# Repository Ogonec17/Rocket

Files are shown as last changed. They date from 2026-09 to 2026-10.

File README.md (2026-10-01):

# PLBP–SG1 · Супер ГИРД

Результаты предварительного проектирования учебной ракеты. **Текущий CAD D01 · расчёты OR04 · подготовка к изготовлению R01 · 1 октября 2026.**

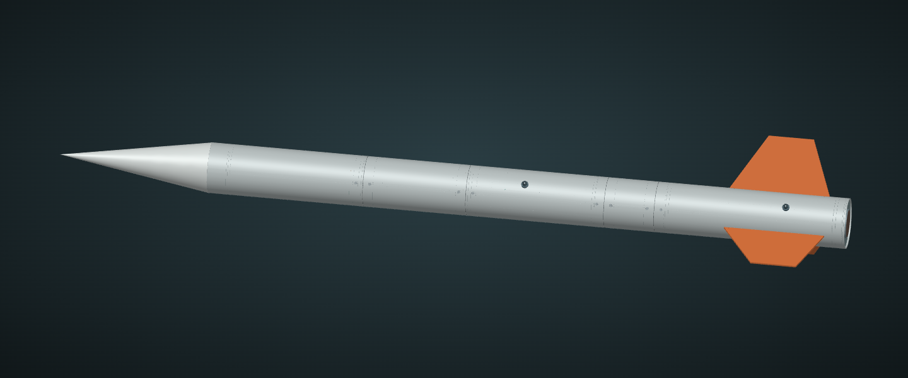
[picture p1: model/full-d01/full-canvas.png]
Модель ракеты PLBP-SG1


## Посмотреть результат

- **[Каталог чертежей DW01](drawings/index.html)** · [общий чертёж](drawings/PLBP-D01-assembly.pdf) · [все детали](drawings/PLBP-D01-parts.pdf).
- **[План сборки](assembly/assembly-plan.pdf)** · [сверка регламента](compliance/compliance-review.pdf) · [скачать комплект](drawings/PLBP-D01-team-pack.zip).

- **[Полная ракета D01: целиком, в разрезе и разнесённо](model/full-d01/viewer.html)**.
- **[Обзор готовности PDF — 6 страниц](readiness/review.pdf)** · [интерфейсы, комплектующие и испытания](readiness/README.md).
- **[Текущие расчёты OR04](simulation/or04/README.md)** — пять сценариев с массой D01.
- [Полный STEP D01](model/full-d01/PLBP-SG1-D01-FULL.step) · [что доработано](model/full-d01/README.md).

- **[Внутренний модуль E02 — предыдущая ревизия](model/internal-e02/viewer.html)** — 3D, материалы и раскрытие кассеты.
- **[Допмиссия M01](mission/m01/README.md)** — схема, алгоритм, компоненты и проверки.
- **[Расчёт OR03 для E02](simulation/or03/README.md)** — масса 5,932 кг, центровка и полёт.

- **[Презентация PDF — этап E02/M01](presentation/PLBP-SG1.pdf)** — краткая версия для команды.
- [PowerPoint](presentation/PLBP-SG1.pptx) · [автономная HTML-презентация](presentation/index.html).
- **[Архивная 3D-модель A04](model/viewer.html)** — вращение, просмотр компоновки, материалы и масса деталей.
- [Модель STEP для FreeCAD и других CAD](model/PLBP-SG1-A04.step) · [размерная схема PDF](model/layout.pdf).

- **[Внутренний модуль E01](model/internal-e01/README.md)** — 3D, размеры, материалы и детали для примерки.
- [15 дополнительных сценариев OpenRocket](simulation/or02/README.md) — влияние массы, поверхности и условий старта.

Для HTML нажмите **Download raw file**, сохраните файл и откройте его в браузере. HTML-презентация, 3D-просмотры и интерактивный отчёт автономны: дополнительные файлы и интернет для просмотра не нужны. GitHub показывает HTML как исходный текст.

## Основные параметры

| Показатель | Текущий проект |
|---|---|
| Полезная нагрузка | 1,5 кг, отдельный макет со своим спасением |
| Расчётная стартовая масса D01 | 6.136 кг, включая полезную нагрузку |
| Длина / диаметр корпуса | 1570 / 100 мм |
| Стабилизаторы | Три, вынос 110 мм |
| Задача миссии | Выведение макета на высоту не менее 1000 м, возврат и сбор данных |
| Дополнительная миссия | Независимый поиск после посадки |

Готовы цифровая компоновка, модель, ведомость масс и предварительные расчётные оценки. Массы пока не измерены. Системы спасения, реальные соединения, электроника, прочность и полёт требуют дальнейшей разработки и испытаний. Расчётный двигатель — справочный образец; конкурсный тип ещё не подтверждён.

## Конкурсная база

В [ТЗ «Супер ГИРД» XV сезона](https://lk.aesa.tech/files/15/ТЗ%20для%20СГ%202026.pdf), п. 1.1.1, масса ракеты не ограничена. При этом PDF задаёт макет **1000 г**, а [страница чемпионата](https://aesa.tech/championship) — **1500 г**. Основной проект использует 1500 г; контрольный вариант 1000 г даёт стартовую массу 5,287 кг. Масса и габарит конкурсного макета требуют подтверждения.

Опубликованное положение относится к сезону 2025–2026. Правила следующего сезона и конкурсный допуск команды ещё не подтверждены. Текущая модель — результат цифрового проектирования, не готовое к полёту изделие.

## Полёт и центровка · OR01

[Модель OpenRocket и инструкция](simulation/README.md) · [интерактивный отчёт](simulation/report.html) · [ведомость масс](simulation/mass-properties.csv).

Пять тестовых сценариев: штиль, ветер 3 и 6 м/с, направляющая 3 м вместо 4 м, контрольный шаг 0,01 с. В штиль: апогей около **1514 м**, max q **26,48 кПа**, стартовый CG **940,3 мм** от носа. Масса и CG модели OpenRocket совпали с CAD; файл повторно загружен и пересчитан.

Результаты относятся к условным входным данным и подъёму до апогея. Отделение, спасение и посадка пока не моделируются. Для открытия нужны оба файла `.ork` и `.rse`; инструкция описывает импорт двигателя. Двигатель справочный, не согласованный с организаторами.

## Уточнение OR02 / E01

[15 дополнительных расчётных случаев](simulation/or02/README.md) · [крепления внутреннего оборудования](model/internal-e01/README.md). E01: прибавка 51,9 г, условная масса ракеты 5,839 кг. Геометрия проверена; соединения, ленты и обслуживание в собранном корпусе ещё открыты. Исходная A04 и OR01 сохранены. Новые расчёты — чувствительность до апогея, не подтверждение полётом.

## Предыдущая ревизия E02 / M01 / OR03

01.10.2026: [внутренние узлы E02](model/internal-e02/README.md), [дополнительная миссия M01](mission/m01/README.md), [расчёт OR03](simulation/or03/README.md). Расчётная масса предыдущей E02 **5,932 кг** с макетом 1,5 кг. A04 и E01 сохранены как предыдущие варианты.

M01 — независимый звуковой поиск: цифровая кассета, кандидаты компонентов, цепи, программа и 17 программных проверок. Аппаратура ещё не собрана; акустический выход через закрытый корпус и зачёт миссии не подтверждены. ТЗ допускает собственный вариант допмиссии, который нужно согласовать.

Порядок следующего этапа: примерка компонентов → фиксация плат/батарей и корпусные стыки → проверка звука и давления → стенд автономности и удержания → полевые поисковые испытания. Геометрия и численный расчёт не заменяют эти проверки.

## Полная сборка D01

01.10.2026: [полная ракета](model/full-d01/viewer.html), [полный STEP](model/full-d01/PLBP-SG1-D01-FULL.step), [детализация и проверки](model/full-d01/README.md). 187 компонентов; расчётная масса 6.136 кг. Включён E02 и доработаны остальные отсеки. Старые массы/полёты E02/OR03 в других разделах относятся к предыдущему варианту.

## Обновление R01 / OR04

01.10.2026: улучшен полный 3D-просмотр D01. [Пакет готовности](readiness/README.md), [обзор PDF](readiness/review.pdf), [актуальные тестовые сценарии OR04](simulation/or04/README.md). Масса 6.136 кг; штилевой апогей 1449.1 м для гладкого контура и расчётного двигателя. Пять сохранённых и повторённых сценариев. Силовые соединения, спасение и основной борт ещё требуют завершения; изготовление и полёт не разрешены этими цифровыми проверками.

## Чертежи DW01 и план сборки AS01

[Общий чертёж — 2 листа A3](drawings/PLBP-D01-assembly.pdf) · [187 позиций, 226 листов](drawings/PLBP-D01-parts.pdf) · [каталог](drawings/index.html). [План сборки](assembly/README.md) связывает все позиции с14 операциями. [Матрица62 проверок регламента](compliance/README.md). Это проектные листы номинальной геометрии; производственные допуски и соединения ещё не выпущены. Физические испытания и допуск не подтверждены.

[Скачать единый комплект для команды](drawings/PLBP-D01-team-pack.zip): чертежи, план и сверка с рабочими локальными ссылками.

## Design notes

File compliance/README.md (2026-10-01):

# Сверка регламента · D01 / DW01 / AS01 / OR04

Проверка 01.10.2026: [официальный каталог](https://aesa.tech/documentation), [страница чемпионата](https://aesa.tech/championship). Повторно получены 9 PDF; все контрольные суммы совпали с изученной базой XV2025–2026. [Реестр источников](sources.json). [Новый XVI сезон анонсирован](https://aesa.tech/season-15-results), но технические правила следующего сезона в проверенном каталоге и поиске не найдены.

**Полное соответствие и конкурсный допуск не подтверждены.** Чертежи не закрывают физические испытания, основной борт, соединения и спасение. Школьный состав команды требует согласования для СГ. Масса макета расходится:1000 г в PDF и 1500 г на странице; проект 1500 г сохраняется до ответа.

[Матрица 62 проверок CSV](requirements.csv) · [Отчёт PDF](compliance-review.pdf) · [чертежи](../drawings/index.html) · [план сборки](../assembly/README.md).

## Как читать статусы

DOCUMENT_AVAILABLE означает наличие файла, DESIGN_ALIGNED — согласованное с пунктом проектное решение. DIGITAL_FIT_ONLY, DESIGN_ONLY, NUMERICAL_ONLY и SOFTWARE_ONLY относятся лишь к названному типу свидетельства. OPEN/EXTERNAL_OPEN/SOURCE_CONFLICT требуют действий. Ни один статус не означает лётный допуск. NOT_APPLICABLE применяется только к условным требованиям, не относящимся к нынешней одноступенчатой схеме с ПУ организаторов.

## Источники

- **REG**: [Положение_15_сезона_ВЧ_ВИШ_2026_от_04_10_2025.pdf](https://lk.aesa.tech/files/15/%D0%9F%D0%BE%D0%BB%D0%BE%D0%B6%D0%B5%D0%BD%D0%B8%D0%B5_15_%D1%81%D0%B5%D0%B7%D0%BE%D0%BD%D0%B0_%D0%92%D0%A7_%D0%92%D0%98%D0%A8_2026_%D0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).
- **APP1**: [Приложение 1 Технические_задания_2026.pdf](https://lk.aesa.tech/files/15/%D0%9F%D1%80%D0%B8%D0%BB%D0%BE%D0%B6%D0%B5%D0%BD%D0%B8%D0%B5%201%20%D0%A2%D0%B5%D1%85%D0%BD%D0%B8%D1%87%D0%B5%D1%81%D0%BA%D0%B8%D0%B5_%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).
- **APP2**: [Приложение 2 Конструкторы 2026.pdf](https://lk.aesa.tech/files/15/%D0%9F%D1%80%D0%B8%D0%BB%D0%BE%D0%B6%D0%B5%D0%BD%D0%B8%D0%B5%202%20%D0%9A%D0%BE%D0%BD%D1%81%D1%82%D1%80%D1%83%D0%BA%D1%82%D0%BE%D1%80%D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).
- **APP3**: [Приложение 3 Регламенты 2026.pdf](https://lk.aesa.tech/files/15/%D0%9F%D1%80%D0%B8%D0%BB%D0%BE%D0%B6%D0%B5%D0%BD%D0%B8%D0%B5%203%20%D0%A0%D0%B5%D0%B3%D0%BB%D0%B0%D0%BC%D0%B5%D0%BD%D1%82%D1%8B%202026.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).
- **APP4**: [Приложение 4 Перечень 2026.pdf](https://lk.aesa.tech/files/15/%D0%9F%D1%80%D0%B8%D0%BB%D0%BE%D0%B6%D0%B5%D0%BD%D0%B8%D0%B5%204%20%D0%9F%D0%B5%D1%80%D0%B5%D1%87%D0%B5%D0%BD%D1%8C%202026.pdf).
- **APP5**: [Приложение 5 Критерии 2026.pdf](https://lk.aesa.tech/files/15/%D0%9F%D1%80%D0%B8%D0%BB%D0%BE%D0%B6%D0%B5%D0%BD%D0%B8%D0%B5%205%20%D0%9A%D1%80%D0%B8%D1%82%D0%B5%D1%80%D0%B8%D0%B8%202026.pdf).
- **APP7**: [Приложение 7 Оргкомитет 2026.pdf](https://lk.aesa.tech/files/15/%D0%9F%D1%80%D0%B8%D0%BB%D0%BE%D0%B6%D0%B5%D0%BD%D0%B8%D0%B5%207%20%D0%9E%D1%80%D0%B3%D0%BA%D0%BE%D0%BC%D0%B8%D1%82%D0%B5%D1%82%202026.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).
- **APP6**: [Приложение_6_Наземные_установки_2026.pdf](https://lk.aesa.tech/files/15/%D0%9F%D1%80%D0%B8%D0%BB%D0%BE%D0%B6%D0%B5%D0%BD%D0%B8%D0%B5_6_%D0%9D%D0%B0%D0%B7%D0%B5%D0%BC%D0%BD%D1%8B%D0%B5_%D1%83%D1%81%D1%82%D0%B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).
- **SG**: [ТЗ для СГ 2026.pdf](https://lk.aesa.tech/files/15/%D0%A2%D0%97%20%D0%B4%D0%BB%D1%8F%20%D0%A1%D0%93%202026.pdf).

## Постатейная проверка

### R01 · Правила соответствующего сезона

Основание: REG, 1.11. Статус: **EXTERNAL_OPEN**.

Свидетельство: Каталог и 9 PDF повторно проверены 01.10.2026; база XV.

Закрытие: Получить ТЗ следующего сезона; XVI анонсирован, технические правила не найдены.

### R02 · Допуск состава команды в СГ

Основание: REG, 4.3.3. Статус: **EXTERNAL_OPEN**.

Свидетельство: Команда школьников; для СГ в положении перечислены другие категории.

Закрытие: Подтвердить допуск у организаторов; не заявлять регистрацию полученной.

### R03 · Капитан, руководитель, регистрация и этапы

Основание: REG, 3;5. Статус: **OPEN**.

Свидетельство: Организационная структура/заявка не предъявлены.

Закрытие: Назначить роли и пройти регистрацию по фактическому календарю.

### R04 · МГМ: масса/габарит/собственное спасение

Основание: SG, 1. Статус: **SOURCE_CONFLICT**.

Свидетельство: CAD 1500 г Ø84×220; PDF 1000 г; сайт 1500 г.

Закрытие: Согласовать массу/габарит; разработать и проверить собственное спасение макета.

### R05 · Высота ≥1000 м

Основание: SG, 1;1.1.2. Статус: **NUMERICAL_ONLY**.

Свидетельство: OR04:1449.1 м штиль со справочным мотором.

Закрытие: Пересчитать с реальным мотором, выступами и площадкой; подтвердить полётом.

### R06 · Лимит массы носителя отсутствует

Основание: SG, 1.1.1. Статус: **DESIGN_ALIGNED**.

Свидетельство: D01:6136.190 г; ограничение 1.5 кг на всю ракету снято.

Закрытие: Измерить массу; сохранять назначение 1.5 кг именно макету.

### R07 · Покупной стандартный двигатель; ΣI≤3000 Н·с

Основание: SG, 1.1.2;3.2.7. Статус: **OPEN**.

Свидетельство: Справочный K535W-REF; реальный мотор неизвестен.

Закрытие: Получить паспорт/кривую и согласовать двигатель; проверить импульс.

### R08 · Возврат:5–10 м/с последние≥10 с

Основание: SG, 1.1.3. Статус: **OPEN**.

Свидетельство: Равновесный CdA в R01; реального спасения нет.

Закрытие: Выпустить систему и протоколы раскрытия/спуска носителя и макета.

### R09 · Особое спасение: индивидуальный допуск

Основание: SG, 1.1.3 прим.. Статус: **CONDITIONAL_OPEN**.

Свидетельство: Тип системы окончательно не выбран.

Закрытие: Если система нестандартная — получить индивидуальный допуск.

### R10 · Температура

Основание: SG, 1.2.1. Статус: **OPEN**.

Свидетельство: Основной борт — концептуальная плата; схема/ПО не выпущены.

Закрытие: Выбрать датчики и алгоритм; определить диапазон/погрешность; провести стенд и запись.

### R11 · Давление

Основание: SG, 1.2.1. Статус: **OPEN**.

Свидетельство: Основной борт — концептуальная плата; схема/ПО не выпущены.

Закрытие: Выбрать датчики и алгоритм; определить диапазон/погрешность; провести стенд и запись.

### R12 · Относительная высота

Основание: SG, 1.2.1. Статус: **OPEN**.

Свидетельство: Основной борт — концептуальная плата; схема/ПО не выпущены.

Закрытие: Выбрать датчики и алгоритм; определить диапазон/погрешность; провести стенд и запись.

### R13 · Кажущаяся скорость по 3 осям

Основание: SG, 1.2.1. Статус: **OPEN**.

Свидетельство: Основной борт — концептуальная плата; схема/ПО не выпущены.

Закрытие: Выбрать датчики и алгоритм; определить диапазон/погрешность; провести стенд и запись.

### R14 · Кажущееся ускорение по 3 осям

Основание: SG, 1.2.1. Статус: **OPEN**.

Свидетельство: Основной борт — концептуальная плата; схема/ПО не выпущены.

Закрытие: Выбрать датчики и алгоритм; определить диапазон/погрешность; провести стенд и запись.

### R15 · Горизонтальное удаление

Основание: SG, 1.2.1. Статус: **OPEN**.

Свидетельство: Основной борт — концептуальная плата; схема/ПО не выпущены.

Закрытие: Выбрать датчики и алгоритм; определить диапазон/погрешность; провести стенд и запись.

### R16 · Регистрация события: Старт

Основание: SG, 1.2.2. Статус: **OPEN**.

Свидетельство: Только общая архитектура.

Закрытие: Определить критерий события, временную метку, память и телеметрию; проверить на стенде.

### R17 · Регистрация события: Апогей

Основание: SG, 1.2.2. Статус: **OPEN**.

Свидетельство: Только общая архитектура.

Закрытие: Определить критерий события, временную метку, память и телеметрию; проверить на стенде.

### R18 · Регистрация события: Команда спасения

Основание: SG, 1.2.2. Статус: **OPEN**.

Свидетельство: Только общая архитектура.

Закрытие: Определить критерий события, временную метку, память и телеметрию; проверить на стенде.

### R19 · Регистрация события: Отделение МГМ

Основание: SG, 1.2.2. Статус: **OPEN**.

Свидетельство: Только общая архитектура.

Закрытие: Определить критерий события, временную метку, память и телеметрию; проверить на стенде.

### R20 · Регистрация события: Посадка

Основание: SG, 1.2.2. Статус: **OPEN**.

Свидетельство: Только общая архитектура.

Закрытие: Определить критерий события, временную метку, память и телеметрию; проверить на стенде.

### R21 · Следующая ступень / её двигатель

Основание: SG, 1.2.2;3.2.6. Статус: **NOT_APPLICABLE**.

Свидетельство: D01 одноступенчатая.

Закрытие: При смене архитектуры повторить аудит; лимит отдельной ступени 2000 Н·с.

### R22 · Собственная приёмная станция

Основание: SG, 1.2.3. Статус: **OPEN**.

Свидетельство: Не изготовлена.

Закрытие: Реализовать радиоканал и наземную станцию; проверить данные и дальность.

### R23 · Память; инерциальная запись≥20 Гц

Основание: SG, 1.2.4;3.3.2. Статус: **OPEN**.

Свидетельство: Массовые габариты памяти и MCU в CAD.

Закрытие: Выбрать аппаратную реализацию; проверить временные метки и целостность 3 ч журнала.

### R24 · Как минимум одна дополнительная миссия

Основание: SG, 2. Статус: **SOFTWARE_ONLY**.

Свидетельство: M01: кассета, отдельное питание,17 программных проверок.

Закрытие: Закончить акустический тракт; аппаратные/поисковые испытания; согласовать зачёт.

### R25 · Повторное применение:≥2 пуска

Основание: SG, 3.1.1. Статус: **OPEN**.

Свидетельство: Цифровая сборка, прототипа нет.

Закрытие: Выпустить ресурсные проверки и процедуру осмотра после первого пуска.

### R26 · Собственный МГМ и отдельная проверка

Основание: SG, 3.1.2. Статус: **OPEN**.

Свидетельство: Носимый макет моделирован; система внутри не закончена.

Закрытие: Изготовить, испытать и отдельно предъявить комиссии.

### R27 · Питание≥3 ч

Основание: SG, 3.1.3. Статус: **OPEN**.

Свидетельство: Основной борт не выбран; для M01 есть сценарий 6 ч.

Закрытие: Испытать основной борт со всеми функциями; M01 не подменяет его энергетическую проверку.

### R28 · Смена≤5 мин либо зарядка без разбора

Основание: SG, 3.1.3. Статус: **OPEN**.

Свидетельство: Выбран путь смены; проход кассеты имеет номинальный зазор 0.2 мм.

Закрытие: Назначить допуски/жгут; выполнить смену питания в закрываемой сборке с таймером.

### R29 · Собственная ПУ: развёртывание/устойчивость

Основание: SG, 3.1.4. Статус: **NOT_APPLICABLE**.

Свидетельство: Планируется ПУ организаторов.

Закрытие: Если выбрана свояПУ: ≤1h развёртывания, устойчивость и фиксация; повторить аудит.

### R30 · Физическая блокировка исполнительных систем

Основание: SG, 3.2.1. Статус: **OPEN**.

Свидетельство: Механизм и электрическая схема не выпущены.

Закрытие: Разработать блокировки; доказать невозможность преждевременного срабатывания.

### R31 · Демонстрация безопасными LED-макетами

Основание: SG, 3.2.1 прим.2. Статус: **OPEN**.

Свидетельство: Предусмотрена в AS01 и R01, не проведена.

Закрытие: Выполнить стендовую демонстрацию по процедуре организаторов.

### R32 · Металл конструкции — только крепления

Основание: SG, 3.2.2. Статус: **DESIGN_ONLY**.

Свидетельство: Конструкционные детали GFRP/PETG; металлический крепёж; материалы условные.

Закрытие: Сверить реальный BOM и назначение металлических элементов; подтвердить материалы.

### R33 · Допустимый оборот компонентов

Основание: SG, 3.2.3. Статус: **OPEN**.

Свидетельство: Окончательной закупочной спецификации нет.

Закрытие: Проверить паспорта/происхождение выбранных компонентов в рамках допуска организаторов.

### R34 · БС 84×30×18 ±1 мм;30 г; фиксация

Основание: SG, 3.2.4. Статус: **DIGITAL_FIT_ONLY**.

Свидетельство: Кассета 87×33×21; максимальный калибр 85×31×19 помещается.

Закрытие: Примерить фактический БС; утвердить ленты/уплотнение и проверить неподвижность.

### R35 · БС вне носа; ≥5D от вершины

Основание: SG, 3.2.4. Статус: **DESIGN_ALIGNED**.

Свидетельство: БС X850; D100; требуемый отступ 500 мм.

Закрытие: Подтвердить фактическую станцию после изготовления.

### R36 · Ударная и тепловая защита БС

Основание: SG, 3.2.4. Статус: **OPEN**.

Свидетельство: Примерочная кассета; силовая и тепловая проверки отсутствуют.

Закрытие: Выпустить крепление/защиту и выполнить предусмотренные испытания.

### R37 · Вентиляция:≥8 отверстий Ø≥1.5

Основание: SG, 3.2.4. Статус: **DESIGN_ONLY**.

Свидетельство: CAD 8×Ø1.6 в X892, равномерно по окружности.

Закрытие: Проверить фактические отверстия и канал давления с закрытым корпусом и M01.

### R38 · Совместимость с ПУ

Основание: SG, 3.2.5;APP6. Статус: **OPEN**.

Свидетельство: Ползуны CAD; рельса ещё неизвестна.

Закрытие: Подтвердить профиль/длину и провести примерку; одно число 30×30 не задаёт паз.

### R39 · Выключатель борта

Основание: SG, 3.3.1. Статус: **OPEN**.

Свидетельство: Доступный внешний интерфейс не выпущен.

Закрытие: Разработать органы управления и проверить доступ в собранном корпусе.

### R40 · Параметры радио отражены в ПЗ

Основание: SG, 3.4.1–2. Статус: **OPEN**.

Свидетельство: Модуль, канал и формат ещё не выбраны.

Закрытие: Зафиксировать частоту/канал, скорость, мощность и контрольную сумму; согласовать рабочий канал.

### R41 · Передача≥5 пакетов/с

Основание: SG, 3.4.3. Статус: **OPEN**.

Свидетельство: Аппаратный канал отсутствует.

Закрытие: Проверить временные метки пакетов на 3 ч стенде и в требуемых условиях связи.

### R42 · Мощность передатчика≤1 Вт

Основание: SG, 3.4.4. Статус: **OPEN**.

Свидетельство: Передатчик не выбран.

Закрытие: Подтвердить настройку и паспорт; ограничениеТЗ не заменяет согласование частоты.

### R43 · Рекомендации: дублёр/формат/мощность

Основание: SG, 3.5. Статус: **RECOMMENDATION**.

Свидетельство: Не превращены в обязательные пороги.

Закрытие: Рассмотреть дублёр, общий формат памяти/радио и минимально достаточную мощность.

### R44 · Готовый конструктор не обязателен для СГ

Основание: APP2, конструкторы. Статус: **DESIGN_ALIGNED**.

Свидетельство: Собственная компоновка D01.

Закрытие: Показать собственные и покупные части; готовый набор не заменяет выполнениеТЗ.

### R45 · Доклад и загрузка материалов

Основание: APP3, ИКК 3;5. Статус: **OPEN**.

Свидетельство: Презентация этапа E02; актуальные чертежи/расчёты выпущены отдельно.

Закрытие: Свести презентацию в одну актуальную ревизию; проверить фактический срок загрузки и 15+15 мин регламент.

### R46 · ПЗ, свидетельства и видео

Основание: APP3, ЗОС 3–5. Статус: **OPEN**.

Свидетельство: Физических протоколов/видео нет.

Закрытие: Подготовить требуемые испытания, материалы и уведомление; общий хронометраж видео≤15 мин.

### R47 · Предстартовая проверка и итоговая защита

Основание: APP3, финал 3–5. Статус: **OPEN**.

Свидетельство: Ни изделие, ниМГМ не предъявлены.

Закрытие: Подать обновлённую ПЗ в установленный срок; предъявить изделие/МГМ/приёмник и устранить замечания.

### R48 · Двигатели организаторов

Основание: APP3, финал 5.3.6. Статус: **EXTERNAL_OPEN**.

Свидетельство: Заявлена поддержка пусков, модель не назначена.

Закрытие: Получить тип и интерфейс; два двигателя нельзя считать безусловной гарантией — число пусков может быть сокращено.

### R49 · Презентация PPTX/PDF

Основание: APP4, СГ: ИКК 1.1;ЗОС 1.2. Статус: **PARTIAL_DOCUMENT**.

Свидетельство: Есть E02/M01; D01/OR04 пока в отдельных материалах.

Закрытие: Согласовать одну актуальную версию для подачи; не маркировать старые слайды как D01.

### R50 · Архитектура, энергетика и алгоритм борта

Основание: APP4, СГ: ИКК 1.2–1.4. Статус: **PARTIAL_DOCUMENT**.

Свидетельство: Частичные материалы; основной борт не реализован.

Закрытие: Завершить схемы/алгоритм; энергобаланс в требуемом табличном и PDF форматах.

### R51 · Расчёт спасения PDF

Основание: APP4, СГ: ИКК 1.5. Статус: **PARTIAL_DOCUMENT**.

Свидетельство: R01 содержит равновесный CdA; раскрытие не рассчитано.

Закрытие: Добавить выбранные купола, нагрузки, укладку, отделение и результаты испытаний.

### R52 · Габаритный чертёж

Основание: APP4, СГ: ИКК 1.6. Статус: **DOCUMENT_AVAILABLE**.

Свидетельство: DW01: общий A3, номинальная геометрия D01.

Закрытие: Утвердить ревизию и размеры перед подачей; статус изготовления не приписывать.

### R53 · Расчёт OpenRocket

Основание: APP4, СГ: ИКК 1.7. Статус: **NUMERICAL_ONLY**.

Свидетельство: OR04:5 сценариев и 5 повторов; реальные входы открыты.

Закрытие: Пересчитать с выбранными компонентами; расширить модель на реальную миссию.

### R54 · Рекомендованы STEP и сборочный чертёж

Основание: APP4, СГ: ИКК 2.2–2.3. Статус: **DOCUMENT_AVAILABLE**.

Свидетельство: Полный STEP D01, DW01 общий вид/сечение, спецификация и AS01.

Закрытие: Выпустить окончательные соединения и допуски; AS01 пока содержит открытые точки.

### R55 · ПЗ и приложения испытаний/процедур

Основание: APP4, СГ: ЗОС 1.1;1.3. Статус: **PARTIAL_DOCUMENT**.

Свидетельство: Рабочие документы; итогового комплекта нет.

Закрытие: Собрать ПЗ в PDF, характеристики, отчёты, предстартовые/послеполётные процедуры.

### R56 · Принципиальная схема

Основание: APP4, СГ: ЗОС 1.5. Статус: **OPEN**.

Свидетельство: Есть концепция M01; основная схема не выпущена.

Закрытие: Выпустить полную принципиальную схему и жгут.

### R57 · Видео спасения, радио и отделения

Основание: APP4, СГ: ЗОС 1.6–1.8. Статус: **OPEN**.

Свидетельство: Нет.

Закрытие: Провести и записать реальные испытания трёх систем.

### R58 · Рекомендован прочностной расчёт

Основание: APP4, СГ: ЗОС 2.1. Статус: **PARTIAL_DOCUMENT**.

Свидетельство: R01: только предварительные ручные оценки.

Закрытие: Назначить нагрузки/материалы, выполнить расчёт и сопоставить с испытаниями.

### R59 · Форматы, повторная подача и сроки

Основание: APP4, общие пп.1–4. Статус: **OPEN**.

Свидетельство: Файлы доступны команде; вЛК не загружались.

Закрытие: Подать материалы заново для этапа; не менять их после закрытия без согласования.

### R60 · Оценка СГ по этапам

Основание: APP5, 6.3. Статус: **PLANNING_ONLY**.

Свидетельство: Матрица задач учитывает механику, электронику, миссии и реальные испытания.

Закрытие: Готовить свидетельства и защиту; оценки экспертов заранее не присваивать.

### R61 · Интерфейс пускового оборудования

Основание: APP6, рельса. Статус: **EXTERNAL_OPEN**.

Свидетельство: Изучено приложение; реальная рельса не получена.

Закрытие: Согласовать поперечник паза/ползунов, длину, угол и контрольную примерку.

### R62 · Контактный и экспертный состав сезона

Основание: APP7, организаторы. Статус: **REFERENCE_ONLY**.

Свидетельство: Приложение XV проверено; технических требований не добавляет.

Закрытие: Использовать актуальный канал связи; сообщения организаторам не отправлялись.

## Приоритетные несоответствия и открытые задачи

1. Согласовать сезонноеТЗ, состав команды, макет, двигатель иПУ.
2. Выпустить силовые соединения, собственное спасение макета и носителя, отделение.
3. Завершить основной борт, питание, запись, радио, наземную станцию и блокировки.
4. Подтвердить канал давления, обслуживание и M01 в закрытом корпусе.
5. Провести испытания, обновить единую презентацию/ПЗ и подать пакет своего этапа.

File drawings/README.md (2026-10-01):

# DW01 · чертежи всей ракеты и каждой позиции

[Общий чертёж — 2 листа A3](PLBP-D01-assembly.pdf) · [альбом деталей — 226 листов](PLBP-D01-parts.pdf) · [каталог](index.html) · [спецификация](catalog.csv) · [комплект ZIP](PLBP-D01-drawings.zip).

187 отдельных PDF, по одному на каждую позицию текущей модели. Повторяющиеся винты и гайки сохраняют собственные позиции; количество в каждой строке — 1. Идентификаторы P001…P187 одинаковы в чертежах, спецификации и плане сборки. Все листы имеют векторный оригинал SVG; PDF не состоит из растровых скриншотов.

## Базы и чтение

Размеры в мм, лист A3 420×297; печать 100%, без подгонки к странице. Масштаб указан у каждого вида. Это независимо подписанные ортогональные проекции X/Y, X/Z, Y/Z и вспомогательная аксонометрия, а не неявная схема расположения видов по стандарту. Пунктир — невидимые рёбра. Числа на габаритных размерных линиях — номинальный габарит в направлении соответствующей проекции; эти размеры справочные. Стрелки и рамка не означают полного соответствия ЕСКД.

Основная система: X от вершины к хвосту; Y/Z — поперечные оси CAD. Для удобства отдельные радиальные детали повернуты вокруг X; угол и последующий перенос начала указаны на листе. Таблицы цилиндрических поверхностей относятся к этой локальной системе. Они задают диаметр и прямую оси L(t)=P+t·a (P — проекция центра поверхности), но не назначают посадку, глубину глухого отверстия или резьбу. Граничный контур следует смотреть на видах и в STEP.

Проекции рассчитаны TechDraw непосредственно из BRep D01. Кривые на векторных листах аппроксимированы полилиниями с отклонением не более 0,025 мм в модельных координатах. Сечение общего чертежа получено пересечением исходной геометрии плоскостью Z=0; элементы вне плоскости не подставлены в него искусственно.

## Статус документации

Это проектные чертежи номинальной геометрии, **не утверждённые производственные чертежи**. Не назначены общие допуски, шероховатость, окончательные материалы/ламинаты, соединения и технология. Нельзя изготовлять по ним условный крепёж, платы-заглушки, складки парашюта, мотор или массовый резерв. Их листы нужны для компоновки и проверки интерфейса. [Плата Adafruit и лицензия источника](CREDITS.md) — покупная сборка с CAD изготовителя; её 58 тел не являются 58 деталями собственного производства.

Расчётная масса физических позиций 5749.163 г. Ещё 387.027 г — шесть нераспределённых бюджетов без геометрии; отдельные чертежи для них не выдуманы. Суммарная масса проекта 6136.190 г. Чертежи не изменяют CAD и массу.

[План сборки](../assembly/README.md) · [проверка требований](../compliance/README.md).

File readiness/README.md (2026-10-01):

# D01 · подготовка к изготовлению / R01

Дата: 01.10.2026. Рабочая конфигурация: полный CAD D01, полезная нагрузка 1500 г, расчётная стартовая масса 6136,190 г, CG 943,921 мм от вершины. Мотор K535W-REF — расчётный образец, не выбранный двигатель.

**Статус: компоновка проверена цифровым способом; производственный выпуск и лётный допуск не получены.** Внешних комплектующих недостаточно для закрытия проекта: необходимо завершить силовые соединения, самостоятельное спасение макета, основной борт и выводы органов управления. Ниже — задания с измеримым результатом, без вымышленных выполненных испытаний.

## Что уже определено

- Габариты 1570 × Ø100 мм; три стабилизатора с выносом 110 мм. 187 компонентов, 244 тела; номинальные пересечения отсутствуют.
- Материалы и массы сведены по деталям; плотности конструкционных материалов пока проектные. Модель изготовителя доступна для Feather RP2040; условные платы явно обозначены.
- Полезная нагрузка 1,5 кг учтена отдельно. Запас в ведомости — распределённые остатки бюджетов, а не доказанный резерв на любые новые узлы.
- Поиск M01: отдельная батарея, алгоритм и 17 программных проверок. Проверка на физической плате и слышимость через закрытый корпус остаются открытыми.
- OR04 синхронизирует массу и осевой центр масс D01 с OpenRocket. Аэродинамика использует гладкий внешний контур: выступы крепежа и направляющих не разрешены. Результаты относятся к подъёму до апогея.

## База требований

[Официальный каталог ВИШ](https://aesa.tech/documentation), [ТЗ Супер ГИРД XV сезона](https://lk.aesa.tech/files/15/ТЗ%20для%20СГ%202026.pdf), [страница чемпионата](https://aesa.tech/championship). Проверено 01.10.2026; доступная база относится к сезону 2025–2026. Требования следующего сезона и допуск школьной команды необходимо подтвердить.

В PDF макет 1000 г, Ø84×220 мм с собственной системой спасения; на странице чемпионата — 1500 г. В проекте сохраняется 1500 г, но окончательное задание и размер следует согласовать. Масса всей ракеты не ограничена. Высота ≥1000 м; суммарный импульс ≤3000 Н·с; минимум два пуска; скорость спуска 5–10 м/с в последние ≥10 с. Эти значения не являются результатами испытаний D01.

## Очерёдность завершения

| Шаг | Конкретный результат | Можно выполнить до получения мотора | Условие закрытия |
|---|---|---|---|
| R1. Требования | Утверждённые сезон, макет, двигатель, рельса и процедура блокировок | Подготовка запросов и таблицы интерфейсов | Ответ организаторов привязан к ревизии проекта |
| R2. Силовая схема | Чертежи всех соединений: хвост → кольца → корпус; стабилизаторы → моторный отсек; фалы → переборки | Выбор схемы и испытание образцов | Назначены материалы, крепления, допускаемые нагрузки и контроль; расчёт сверён с испытаниями |
| R3. Спасение | Два самостоятельных комплекта: носитель и макет; укладка, фалы, крепления, механизм разделения | Макеты отсеков и примерка выбранных куполов | Показано извлечение без зацепов, затем подтверждены раскрытие и скорость спуска |
| R4. Основной борт | Принципиальная схема, полный жгут, блокировки, ПО, наземная станция | Да | Стендовые протоколы питания, данных, записи и LED-имитации исполнительных каналов |
| R5. Обслуживание и M01 | Доступные выключатели, смена батарей, защищённый звуковой выход | Да, на отдельном макете корпуса | Смена батареи ≤5 мин; поиск в закрытом корпусе; давление у самописца не искажено новым трактом |
| R6. Производственный выпуск | Чертежи с допусками, технологией и спецификацией реальных деталей | Частично | Никаких условных габаритов в силовых и исполнительных узлах; выполнен независимый обзор |
| R7. Приёмка и сборка | Измеренные массы/CG/габариты и фактическая конфигурация ORK | После комплектования | Ведомость обновлена; интерфейсы совпадают; пройдены наземные проверки |
| R8. Допуск | Протоколы наземных испытаний и решение комиссии | Нет | Закрыты замечания, проверены реальные условия запуска |

## Конструкторские решения, которые нельзя подменять детализацией картинки

**Стыки корпуса.** В D01 стоят втулки Ø96,4/94×40 мм, условные винты M3 и круглые гайки. Требуется определить удержание гаек, доступ инструмента, фактическую длину зацепления резьбы, смятие/вырыв композита и передачу изгиба. Зазор 0,3 мм на сторону между втулкой и корпусом — номинальный, без допусков. Замена гайки на закладную должна пройти повторную проверку массы и пересечений.

**Хвост.** Посадочная труба Ø58/54,8×375 мм и габарит мотора Ø54×358 мм не задают фиксацию двигателя. Удержание и тепловая защита проектируются по инструкции конкретного покупного двигателя. Корневые части стабилизаторов входят в прорези корпуса, но соединение с трубой/кольцами и его прочность ещё не определены. Зазор 0,2 мм не является назначенным клеевым швом.

**Спасение.** Восемь складок в CAD — иллюстрация укладки. Нет выбранного купола, расчётных нагрузок раскрытия, спецификации фалов и законченного отделения. Равновесная оценка CdA из расчётного приложения помогает выбрать диапазон куполов, но не определяет усилие раскрытия. Макет должен иметь собственный комплект; размещённый внутри резерв массы не заменяет этот комплект.

**Электроника.** Основная плата и контроллер спасения пока объёмные макеты. Требуется выбрать датчики/радио/питание, выпустить схему и определить положение антенны. Предусмотреть съёмные разъёмы с фиксацией, защиту проводов от перетирания и маркировку каждого конца. Исполнительные выходы сначала проверяются на безопасных светодиодных эквивалентах.

**M01 и давление.** Отверстия внутри кассеты не выводят звук наружу. Следующее решение — отдельный акустический тракт к оболочке с защитой от попадания воды и отделением от измерительного объёма самописца. Пока его геометрия и материал мембраны не выбраны, нельзя утверждать дальность поиска. До вырезания отверстий нужен макет тракта: сравнить слышимость в закрытом корпусе и реакцию канала давления. Наружная кнопка/индикатор также требуют законченного интерфейса. Проектные цели 10 и 25 м проверяются после установки всего отсека.

## Комплект выпуска

- `interfaces.csv` — размеры, зависимость от комплектующих и документ, закрывающий каждый интерфейс.
- `procurement.csv` — позиции, которые надо выбрать/подтвердить; состояние «кандидат» не означает разрешение закупки.
- `ground-tests.csv` — методы и критерии приёмки; все физические проверки имеют статус NOT_RUN.
- `test-record.csv` — пустая форма измерений, конфигурации и заключения.
- [Расчётные таблицы](engineering.csv) и [обзор PDF](review.pdf) — предварительные расчёты по текущей массе и сценариям OR04.

Сначала закрываются R1–R6. Только после этого состояние проекта можно назвать «ждём комплектующие для испытаний». Часть работы можно вести параллельно в команде, но менять массу, крепления и отверстия без обновления CAD/ведомости/расчётов нельзя.

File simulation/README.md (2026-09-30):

# Полёт, центровка и давление · A04 / OR01

**Тестовый расчёт OpenRocket 24.12, до апогея. Полезная нагрузка 1,5 кг.** Площадка, реальная направляющая и двигатель организаторов неизвестны. Это предварительные сценарии, а не прогноз согласованного пуска.

- [Интерактивный отчёт с графиками](report.html): скачать файл и открыть в браузере; данные встроены.
- [Модель OpenRocket](PLBP-SG1-A04-OR01.ork) и обязательный [справочный двигатель](K535W-REF.rse).
- [Краткая таблица результатов](summary.csv) · [ведомость масс и центров деталей](mass-properties.csv).
- Полные временные ряды: [штиль](calm.csv), [ветер 3 м/с](wind3.csv), [ветер 6 м/с](wind6.csv), [направляющая 3 м](short_guide.csv), [шаг 0,01 с](fine_step.csv).

## Открытие и повторный расчёт

1. Установить [официальный OpenRocket 24.12](https://github.com/openrocket/openrocket/releases/tag/release-24.12). Готовый пакет содержит Java.
2. Сохранить `.ork` и `.rse`. Поместить `.rse` в папку пользовательских кривых тяги: в **Edit → Preferences → General → User-defined thrust curves** добавить папку с этим файлом. Перезапустить OpenRocket, чтобы он прочитал базу двигателей. В 24.12 кривая не встроена в `.ork`.
3. Открыть `.ork`. В конфигурации двигателя должен быть **PLBP Reference / K535W-REF**. Не подменять его одноимённым мотором из другой базы: это изменит исходные данные. Если программа сообщает об отсутствующем двигателе, сначала проверить импорт `.rse`.
4. Во вкладке **Flight simulations** сохранены пять сценариев с результатами. Выделить сценарий, выбрать **Run simulations**. Для графиков — **Plot / export**: CG location, CP location, stability margin, air pressure, Mach number и другие параметры.
5. Во вкладке **Simulation options → Simulation extensions** используется **Java class: info.openrocket.core.simulation.listeners.system.ApogeeEndListener**. Этот класс входит в официальный OpenRocket 24.12; дополнительный плагин не нужен. Он останавливает расчёт после обнаружения апогея. Удалять его имеет смысл только после разработки и добавления спасения.

Модель повторно открыта и пересчитана в новом процессе официального ядра 24.12. Предупреждение **“No recovery device defined in the simulation”** ожидаемо: объём спасения учитывается как масса, действующий парашют ещё не задан. Это предупреждение сохранено, а не скрыто.

## Что заложено в модель

| Вход | Принято для теста |
|---|---|
| Геометрия | A04: длина 1570 мм, Ø100 мм; конический нос 300 мм; 3 стабилизатора 200/90/70/110 × 3 мм |
| Стартовая масса / после выгорания | 5,787092 / 5,042092 кг, включая макет 1,5 кг |
| CG от вершины на старте / после выгорания | 940,325 / 873,735 мм |
| Материалы оболочек | Стеклопластик 1850 и полимер 1270 кг/м³ — принятые плотности, не измерения |
| Модель атмосферы | ISA, высота старта 0 м; стандартные 288,15 K и 101325 Па у уровня моря |
| Условные координаты | 45° с. ш., 0° долготы; сферическая Земля; это не предлагаемая площадка |
| Направляющая | Вертикально; 4 м эффективного направленного хода, отдельный тест 3 м |
| Ветер | Постоянный 0 / 3 / 6 м/с, направление потока 90° в соглашении OpenRocket; турбулентность 0 |
| Численный шаг | Максимальный шаг 0,02 с; контроль 0,01 с. Внутренние адаптивные шаги могут быть меньше |
| Поверхность | Normal; профиль стабилизаторов Square; реальные дефекты и выступающие крепления не определены |
| Массовая модель | Масса и CG каждой детали из CAD/ведомости; внутренние блоки заменены цилиндрическими сосредоточенными массами |
| Область расчёта | Одна жёсткая сборка до апогея; макет удерживается внутри |

Длина 4 м — условный эффективный ход. Реальная полезная длина рельса, положение направляющих элементов и их аэродинамика требуют согласования. В этой ревизии геометрия направляющих элементов не добавлена.

Внешняя аэродинамическая форма перенесена в компоненты OpenRocket. Массовые поправки отдельных деталей обеспечивают совпадение массы и продольного CG с CAD; фиксированная масса всей ракеты не задавалась. Поэтому расход двигателя сдвигает CG. Моменты инерции внутренних блоков приближённые; малое поперечное смещение CG около 0,254 мм сохранено в массовой модели, но это не доказывает полную модель динамики асимметрии.

## Двигатель — только справочный вход

Файл **K535W-REF.rse** содержит оцифрованную кривую коммерческого AeroTech K535W из [брошюры производителя](https://d3l66gvjdr7rqw.cloudfront.net/Templates/170652/myimages/dms%20brochure%202021-ldrs-39%20small_1656455641142.pdf). Это не сертифицированный файл и не выбор конкурсного двигателя. Масса загруженного двигателя 1264 г, расходуемая масса 745 г, Ø54 × 358 мм взяты как проектный справочный вариант; [карточка производителя](https://aerotech-rocketry.com/products/product_79e0eada-ff52-f94c-c6ad-1fdd480dbc43).

Интеграл оцифрованной кривой **1422,716 Н·с**, паспортный ориентир 1434 Н·с: расхождение −0,79%. Растровая оцифровка даёт пик около 712 Н вместо каталожных 655 Н; следовательно, расчёт ускорений и схода особенно чувствителен к замене исходной кривой. Таблица заканчивается на 2,765625 с. Расход массы считается пропорциональным накопленному импульсу, CG двигателя принят посередине корпуса и не перемещается внутри него. Событие вышибного заряда не моделируется. Геометрия двигателя внутри и его изготовление не входят в проект этой интеграции.

## Результаты

| Тест | Апогей, м | max q, кПа | Скорость схода, м/с | Смещение у апогея, м |
|---|---:|---:|---:|---:|
| Штиль · 4 м | 1514 | 26,48 | 29,3 | 1,5 |
| Ветер 3 м/с · 4 м | 1508 | 26,50 | 29,3 | 125,2 |
| Ветер 6 м/с · 4 м | 1489 | 26,55 | 29,3 | 241,9 |
| Ветер 3 м/с · 3 м | 1507 | 26,50 | 25,6 | 133,5 |
| Штиль · шаг 0,01 с | 1514 | 26,48 | 29,3 | 1,5 |

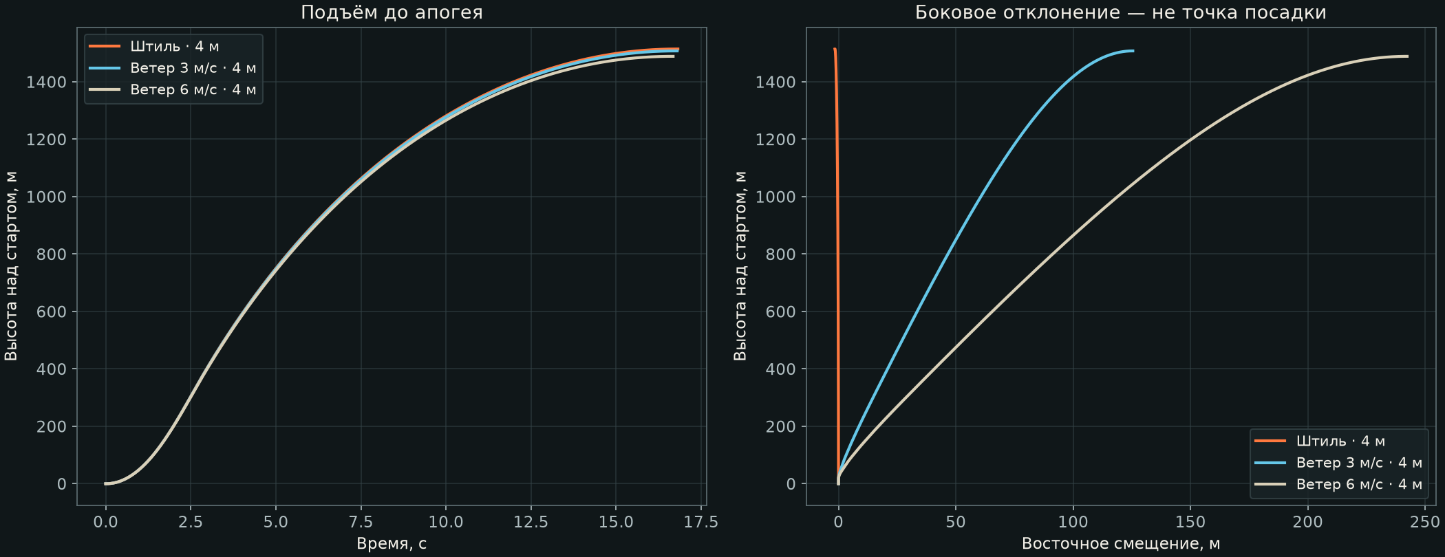
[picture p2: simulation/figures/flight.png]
Траектории тестовых сценариев


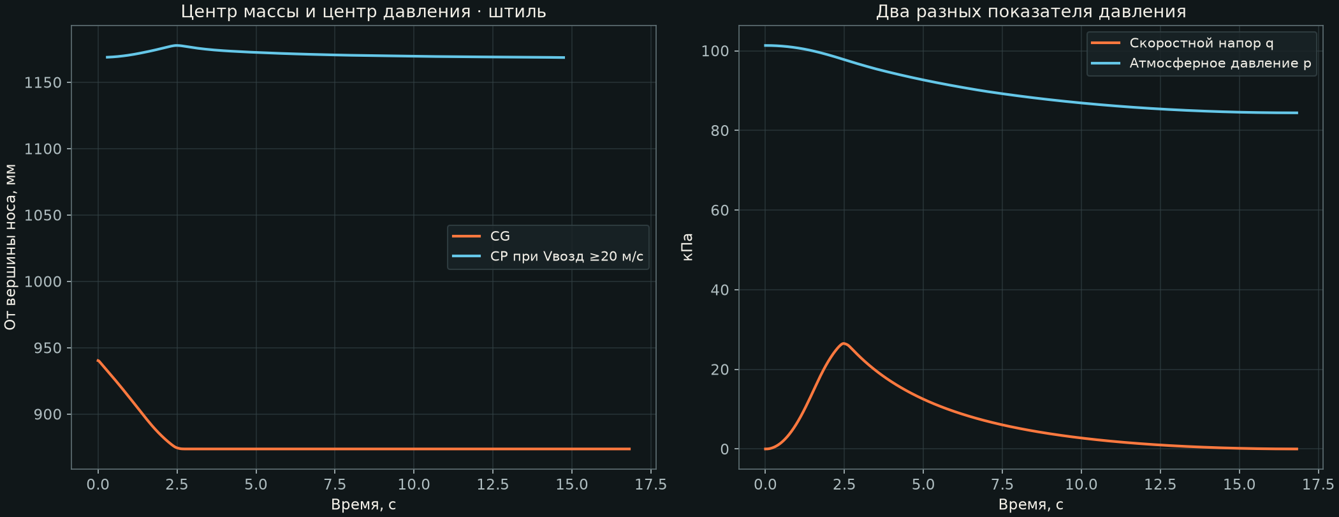
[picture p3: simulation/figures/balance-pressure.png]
Центровка, атмосферное давление и скоростной напор


Высоты даны над стартом. **Смещение у апогея не является местом посадки.** Для 6 м/с минимум расчётного запаса после схода при Vвозд ≥20 м/с составляет 1,515 диаметра, максимальный угол атаки в этом интервале — 11,5°. Это требует проверки динамики и применимости аэродинамической модели; отсутствие предупреждения симулятора не означает допуск. Неизвестная турбулентность и порывы в этих пяти сценариях отсутствуют.

В штиль max q = **26,48 кПа** при t ≈ 2,47 с, h ≈ 298 м. Максимальное число Маха 0,622. Атмосферное давление у апогея около 84,41 кПа.

## Центр масс, центр давления и запас

CG = Σ(mᵢxᵢ)/Σmᵢ. Координата x отсчитывается от вершины носа к хвосту. На старте CG = 940,325 мм; после выгорания 873,735 мм: расход массы сзади смещает центр вперёд. В [ведомости](mass-properties.csv) каждая деталь и двигатель учтены один раз; суммарно 5,787092 кг. Макет 1,5 кг — часть этой массы.

CP — точка результирующей нормальной аэродинамической силы в принятой модели. **CP не постоянен.** В статической оценке OpenRocket при M=0,05, α=0°, азимуте потока 0°: CP = **1168,8 мм**, запас (CP−CG)/D = **2,285 D**, где D=100 мм. Предыдущая ручная низкоскоростная оценка давала 1168,8 мм и 2,285 D; это другой уровень приближения, её не подгоняли к OpenRocket.

| Число Маха | Угол атаки, ° | CP от носа, мм | Запас при стартовом CG, D |
|---|---:|---:|---:|
| 0,05 | 0 | 1168,8 | 2,285 |
| 0,05 | 5 | 1124,7 | 1,844 |
| 0,05 | 10 | 1092,3 | 1,520 |
| 0,30 | 0 | 1170,5 | 2,302 |
| 0,30 | 5 | 1126,4 | 1,861 |
| 0,30 | 10 | 1094,0 | 1,537 |
| 0,60 | 0 | 1176,8 | 2,365 |
| 0,60 | 5 | 1132,8 | 1,924 |
| 0,60 | 10 | 1100,2 | 1,599 |

Положительный статический запас сам по себе не подтверждает устойчивость на направляющей, при порывах, больших углах атаки, отделении или флаттере. В графиках CP скрыт при Vвозд <20 м/с, чтобы низкоскоростную область возле апогея не принимать за надёжный показатель; исходный CSV сохранён полностью.

## Давление: три разных величины

- **Атмосферное p**, Па: давление окружающего воздуха. Меняется с высотой; для нагрузки на замкнутую оболочку нужна разность наружного и внутреннего давления. Внутреннее давление, продувка вентиляционных отверстий и переходные процессы не рассчитаны.
- **Скоростной напор q = ½ρVвозд²**, Па: масштаб аэродинамических нагрузок. Использована скорость относительно воздуха `Mach × speed_of_sound`, а не скорость относительно земли. График q не показывает локальную нагрузку каждой точки корпуса.
- **Местное давление на поверхности** требует распределения коэффициента давления, CFD или испытаний. Его здесь нет. Центр давления CP — координата, а не величина давления. Давление в двигателе не является входом этого расчёта: двигатель задан готовой кривой тяги.

## Проверки и пределы точности

Повторная загрузка `.ork` + `.rse`: без предупреждений загрузчика; пять сценариев пересчитаны; массы и продольный CG совпали с CAD до 10⁻⁸ кг/м. Это проверка переноса данных, а не точность реального изделия. Полные CSV проверены на конечность основных величин, физические знаки и массу после выгорания. Остановка после апогея сохранена в файле и повторно проверена.

При изменении шага 0,02 → 0,01 с изменение апогея составляет **0,0161 м** (0,00107%), max q — **0,402 Па**. Сравнение двух шагов даёт оценку чувствительности; оно не устанавливает порядок сходимости и не подтверждает реальный полёт.

Автоматический контроль использует seed **20260930**. В 24.12 seed не сохраняется в формате `.ork` 1.10, а ядро добавляет малые случайные моменты даже при нулевой турбулентности; повтор в GUI может немного отличаться. Сохранённые данные в `.ork` соответствуют приложенным CSV. Пакет не зависит от внешнего кода для остановки на апогее: использован штатный класс симулятора.

Это шестистепенная модель жёсткого тела с инженерной аэродинамической моделью OpenRocket, а не CFD, прочностной анализ или модель гибкой конструкции. Старый вертикальный расчёт при заданных Cd остаётся отдельной оценкой чувствительности и не смешан с новой таблицей. Отделение 1,5 кг и два парашюта нужно разработать до расчёта спуска и зоны посадки.

Для повышения достоверности нужны: согласованный двигатель с проверенной кривой тяги/массы; измеренные масса, CG и инерция сборки; реальная направляющая; метеопрофиль; геометрия креплений; стендовые проверки отделения и раскрытия; сопоставление расчёта с телеметрией испытаний.

Источники методов: [документация OpenRocket](https://openrocket.readthedocs.io/en/latest/user_guide/advanced_flight_simulation.html), [техническое описание](https://openrocket.sourceforge.net/techdoc.pdf), [штатная остановка на апогее в 24.12](https://github.com/openrocket/openrocket/blob/release-24.12/core/src/main/java/info/openrocket/core/simulation/listeners/system/ApogeeEndListener.java). Документация latest может описывать функции новее 24.12; данный файл проверен именно в 24.12.

CSV: все заголовки содержат SI-единицы; `aoa_rad` и угловые скорости — радианы, `stability_cal` — диаметры корпуса, `cg_m`/`cp_m` — от носа, `east_m`/`north_m` — локальное смещение, `ground_speed_m_s` — полная скорость относительно земли, `air_speed_m_s` — относительно воздуха. `q_Pa` вычислен из выходов атмосферы и числа Маха OpenRocket; остальные столбцы — выходы симулятора. Больше знаков в CSV нужно для воспроизводимости, а не для обещания такой точности.

## Расширение OR02

[Новая серия из 15 расчётных случаев](or02/README.md): поверхность, температура, высота площадки, запас массы, профили ветра и примерочный E01.

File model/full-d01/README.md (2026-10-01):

# D01 · полная детализированная ракета

**Полная сборка в миллиметрах, масштаб 1:1.** Это следующая цифровая ревизия после отдельного модуля E02. Внешние основные размеры: длина 1570 мм, корпус Ø100 мм, три стабилизатора с выносом 110 мм.

[Открыть полную 3D-модель](viewer.html) · [полный STEP](PLBP-SG1-D01-FULL.step) · [размерная схема PDF](layout.pdf) · [все детали и остатки бюджетов](parts.csv) · [масса по подсистемам](mass-totals.csv).

Просмотр работает без сети и внешних библиотек. WebGL со сглаживанием и разрешением экрана; при недоступности графического контекста включается резервный CPU-рендер. Режимы: целая ракета, продольный разрез, разнесение подсистем. Подсистемы можно скрывать; выбор отдельной детали приближает её. Shift + мышь перемещает камеру; доступны виды сбоку/объёмный, вписывание, полный экран и три уровня качества. Стрелки и +/− работают при фокусе на модели. Перерисовка происходит по действию пользователя, без постоянного цикла в фоне. Разрешение ограничено 1 / 3,2 / 6 млн пикселей для экономного / автоматического / высокого качества; высокое даёт дополнительное сглаживание на обычном экране. Большая детализация может требовать нескольких секунд при первом открытии на слабом ПК. На GitHub сначала скачать HTML через Download raw file. В исходном проекте дополнительно выпущены нативные FreeCAD для полной сборки и разреза, с сохранённой историей построения.

Полная ракета

## Реальная детализация этой ревизии

- **Корпус:** пять отдельных секций, четыре соединительные втулки, швы с прокладками, отверстия, винты с углублениями под ключ и ответные гайки. Их номинальная посадка проверена; резьба не моделируется, способ удержания гаек и рабочие нагрузки ещё не назначены.
- **Обтекатель:** полая оболочка, посадочная юбка, переборка, шайба и габарит рымового интерфейса. Соединение и система возврата требуют силовой проверки.
- **Полезная нагрузка:** оболочка Ø84×220, две съёмные крышки, четыре стойки и винты, опора и направляющие. Внутри явно сохранён резерв объёма/массы под собственную систему и балансировку. Это проект собственного макета, не утверждённая конструкция организаторов.
- **Спасение:** мешок, торцевые элементы, восемь условных складок купола и две ленты. Модель показывает расположение, но не предсказывает деформации ткани и раскрытие. Фалы, точки удержания и исполнительный механизм ещё не выпущены.
- **Электроника:** весь E02 включён в ракету. Основной борт и отдельный блок спасения получили корпуса, крышки и концептуальные платы размещения. Трасса основного питания показана двумя отдельными проводами с выходами через соединители. Основная схема и полный жгут остаются открытыми.
- **M01:** вместо простого габарита Feather использован [STEP Adafruit](CREDITS.md), включая USB-разъём, отверстия и электронные компоненты. Геометрия изготовителя не масштабировалась; её посадка в кассете проверена. Батарея, плата ключа и излучатель остаются в собственной кассете. Слышимость через корпус по-прежнему требует стенда.
- **Хвост:** моторная труба, кольца с технологическими отверстиями, ответная хвостовая плита и сквозные корневые части трёх стабилизаторов. Двигатель остаётся закрытым паспортным габаритом покупного изделия. Реальный удерживающий узел зависит от двигателя организаторов.
- **ПУ:** две площадки по кривизне корпуса, ползуны и крепёж. Размеры ползунов проектные; совместимость с реальной направляющей не объявлена.

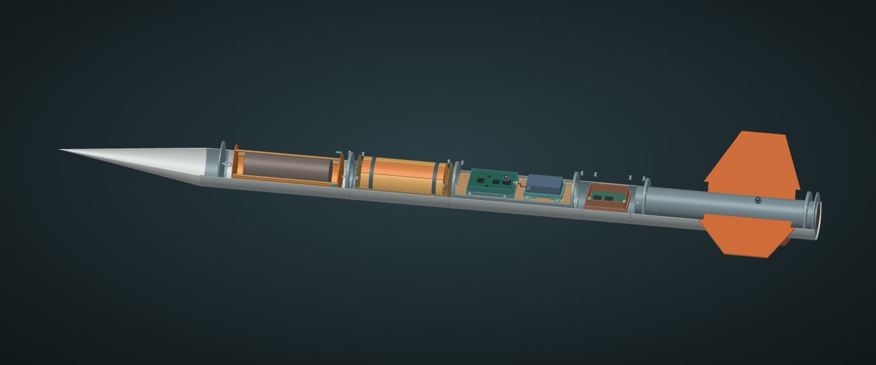
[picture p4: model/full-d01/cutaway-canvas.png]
Продольный разрез


## Масса и материалы

Текущая расчётная масса полной ракеты: **6.136 кг**, включая **1,5 кг полезной нагрузки**. Центр масс: **943.921 мм от вершины**. Изменение к E02: **+204.399 г**. Новые стыки, корни стабилизаторов и опоры имеют массу; высокая детализация не означает сохранение старой оценки 5,932 кг.

Плотности конструкционных деталей — допущения: стеклопластик 1,85 г/см³, полимер PETG 1,27 г/см³, условная сталь крепежа 7,85 г/см³. Для покупных сборок и ткани применяются назначенные массы, не плотность монолитного тела.

Бюджеты нагрузки 1500 г, основного борта 180 г, блока спасения 150 г и укладки 300 г распределены между деталями и явными остатками. Новые винты, гайки и показанные кабели выделены из прежних 120 г общего резерва. В `parts.csv` остатки имеют тип `unmodelled_allowance`; их нельзя добавлять второй раз. Массы не взвешены; распределение массы электроники и ткани ещё приблизительное. MassAudit — снимок этой ревизии: после изменения размеров пересчитать ведомость, она не обновляется автоматически от ручного редактирования.

## Проверено

187 компонентов, суммарно 244 отдельных твёрдых тел, включая тела из сборки производителя. Геометрия валидна; межкомпонентных объёмных пересечений нет. Нативный файл повторно открыт, видимость всех компонентов и трёх стабилизаторов проверена в GUI. STEP повторно импортирован с контролем количества тел и объёма. Изменение выноса пера через параметр и возврат исходного значения проверены.

Отдельные детали платы производителя учитываются как одна покупная сборка; внутренняя технологическая корректность её STEP не является нашей проверкой производства платы. Изображение высокой детализации не подтверждает силовую работоспособность ракеты.

## Что ещё открыто

Конструкция стыков и фиксация закладных гаек, удержание полезной нагрузки и двигателя, соединение корней стабилизаторов, силовые точки и фалы спасения, реальный полный жгут, испытания доступа/обслуживания, прочность и вибрация. Зазоры в CAD номинальные; реальные допуски материалов и печати ещё не учтены. Стыки и прокладки меняют утечки общего объёма — требуется повторная проверка канала давления самописца. Произвольный перенос отверстий не допускается без пересмотра измерительной схемы.

Предыдущие расчёты OR03 относятся к E02. В OR04 масса и осевой CG синхронизированы с D01; гладкий внешний контур сохранён, сопротивление новых выступов ещё не учтено. OR04 — тестовая оценка до апогея, не расчёт полной миссии. Сегменты корпуса и разнесённый просмотр не определяют автоматически места/механизм отделения в полёте.

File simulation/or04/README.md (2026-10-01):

# OR04 · масса D01 в OpenRocket

[Открыть ORK](PLBP-SG1-D01-OR04.ork) · [сводная таблица](summary.csv) · [сравнение](comparison.png).

OpenRocket 24.12; масса 6.136190 кг; CG 943.921388 мм. Все массы D01 перенесены из ведомости; двигатель добавлен ровно один раз. Масса после выгорания 5.391190 кг. Пять сценариев, пять повторов после загрузки ORK; расхождение апогеев менее 0,001 м. При шаге 0,01 вместо 0,02 с изменение апогея 0.012201 м. Это проверка воспроизводимости, не физическая валидация.

| Сценарий | Ветер, м/с | Рельса, м | Апогей, м | q, кПа | Сход, м/с |
|---|---:|---:|---:|---:|---:|
| calm | 0 | 4 | 1449.1 | 23.71 | 28.26 |
| wind3 | 3 | 4 | 1442.3 | 23.73 | 28.26 |
| wind6 | 6 | 4 | 1423.1 | 23.78 | 28.25 |
| rail3 | 0 | 3 | 1449.1 | 23.71 | 24.80 |
| fine | 0 | 4 | 1449.1 | 23.71 | 28.26 |

**Область применимости:** гладкий внешний контур A04, текущие массы и осевые центры D01. Выступающие головки винтов, направляющие и швы не разрешены в аэродинамике. Малые цилиндрические массовые элементы воспроизводят массу и центры, но не точные тензоры инерции. Ветер постоянный; турбулентность отключена. Нельзя считать этот набор исчерпывающим или прогнозом реального запуска.

Двигатель — K535W-REF: оцифрованная иллюстративная кривая, не сертифицированный файл выбранного мотора. ISA, площадка 0 м, широта 45°, вертикальная рельса; seed 20260930. Мотор, площадка, рельса неизвестны. ORK 24.12 не сохраняет этот seed; повтор в GUI может немного отличаться.

Расчёт останавливается у апогея. Предупреждение об отсутствии спасения ожидаемо и сохранено. Нет отделения макета, спуска, раскрытия, флаттера и прочностной оценки. Использовать только для сравнения тестовых сценариев. Старые OR01–OR03 сохранены как история.

[Техническая документация OpenRocket](https://openrocket.info/documentation.html).

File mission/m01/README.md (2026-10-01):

# M01 · автономный поиск ракеты звуком

**Реализован программный прототип и цифровая компоновка. Аппаратура ещё не собрана и не испытана; зачёт дополнительной миссии не получен.** M01 остаётся отдельной системой поиска с собственным питанием. В этой ревизии выбран звуковой маяк для ближнего поиска; светодиод служит диагностике и визуальному обнаружению при открытой оптической линии. Это не GPS-трекер и не радиопеленгатор; координаты M01 не передаёт.

Раздел 2 [ТЗ XV сезона «Супер ГИРД»](https://lk.aesa.tech/files/15/%D0%A2%D0%97%20%D0%B4%D0%BB%D1%8F%20%D0%A1%D0%93%202026.pdf) требует минимум одну дополнительную миссию, допускает собственный вариант и приводит независимый поиск без прямой видимости как пример. Акустическая реализация — решение проекта, а не дословно названное в ТЗ устройство. До включения в конкурсную заявку нужно согласовать её содержание и критерий зачёта. На 01.10.2026 [официальный каталог](https://aesa.tech/documentation) продолжает ссылаться на XV сезон; условия нового сезона не подтверждены.

## Цель и границы

Найти скрытый травой или кустарником носитель в зоне, до которой команда дошла по основной телеметрии либо поисковой сетке. M01 должен продолжать работу при отключённых основном борте и его батарее. Проектная цель: **6 часов суммарно с момента включения**, включая ожидание старта; проверка поиска с 10 м и затем с 25 м при отсутствии прямой видимости. Это цели натурной проверки, не обещанная дальность. Ветер, фон, положение корпуса, растительность и закрытый корпус могут резко ухудшить слышимость.

M01 не определяет посадку. После снятия отдельной петли INHIBIT и её устойчивого размыкания на 2 с запускается задержка 300 с; затем повторяется звуковой рисунок. При затяжном ожидании маяк начнёт звучать ещё на земле. Это намеренный резервный режим, который не зависит от датчика или команды основного борта. Он не выдаёт команд на спасение, отделение или двигатель.

## Состав стендового варианта

| Позиция | Компонент / значение | Основание и статус |
|---|---|---|
| U1 | Adafruit Feather RP2040 #4884 | [Производитель](https://www.adafruit.com/product/4884): 51×23×7,5 мм. Кандидат, экземпляр не приобретён; монтаж и доступ к USB нужно проверить |
| BT1 | Adafruit #258, 1S LiPo 1200 мА·ч с PCM | [Страница](https://www.adafruit.com/product/258): 23 г; [TDS](https://cdn-shop.adafruit.com/product-files/258/C101-_Li-Polymer_503562_1200mAh_3.7V_with_PCM_APPROVED_8.18.pdf): минимум 1140 мА·ч, рисунок 62±0,3 ×35±0,3 ×5±0,3 мм. В CAD принят максимум 62,3×35,3×5,3; провода и разъём в этот прямоугольник не входят |
| BZ1 | Same Sky CMI-1295-85T | [TDS изготовителя](https://jp.sameskydevices.com/product/resource/cmi-1295-85t.pdf): активный магнитный индикатор, номинально 3 В, рабочие 2–5 В, 1,6 г. Межосевое расстояние выводов 7,6 мм. Паспортный уровень звука относится к 10 см и открытой установке |
| Q1 | AO3400A, N-MOSFET, SOT-23 | [TDS](https://www.aosmd.com/sites/default/files/res/datasheets/AO3400A.pdf): ключ имеет характеристику при Vgs=2,5 В. G=1, S=2, D=3; сверить корпус и разводку перед пайкой |
| D1 | SS14, защитный диод | Катод к +3,3 В, анод к отрицательному выводу BZ1; конкретный изготовитель и посадочное место требуют фиксации |
| R1 / R2 | 100 Ом / 100 кОм | Последовательно с затвором / затвор–исток; номиналы проекта |
| R3 / LED1 | 470 Ом / зелёный LED 3 мм | Диагностика, токовый бюджет 3 мА; артикул LED и внешний световод открыты |
| C1 / C2 | 100 нФ / 47 мкФ, ≥6,3 В | Между +3,3 В и местной землёй рядом с ключом; полярность C2 учитывать |
| S1 / S2 / S3 | Питание EN / петля INHIBIT / кнопка TEST | Доступ снаружи обязателен; тип разъёмов, панели и герметизация ещё не выпущены |

Feather #4884 и батарея #258 — конкретные кандидаты, не утверждённый закупочный список. Наличие в регионе, фактические размеры партии и соединители предстоит проверить. Не подменять JST-соединитель внешне похожим без проверки полярности: рисунок батареи и реальный жгут должны быть сверены с маркировкой платы.

## Соединения

[Таблица цепей](wiring.csv) · [структурная схема](wiring.svg) · [алгоритм](states.svg).

BAT1 подключается к штатному батарейному входу U1. Сигнальная часть питается от 3,3 В U1. [Руководство платы](https://learn.adafruit.com/adafruit-feather-rp2040-pico/pinouts) описывает EN и выводы; EN, замкнутый на местную GND, отключает стабилизатор, но не разрывает все цепи батареи и зарядки. Для замены батареи разъединить её разъём; USB при полётной работе отсоединён.

У M01 **нет соединения с питанием, землёй или шиной основного борта в полётной конфигурации**. D6 замыкается петлёй на местную землю для запрета работы. D12 замыкается кнопкой TEST. D5 управляет затвором Q1, а не катушкой напрямую; D9 включает LED через R3. Внутренние подтяжки задаются программно. На стенде проверить устойчивость этих входов с реальной длиной проводов.

Плата ключа в CAD имеет номинальные отверстия Ø1 мм с шагом 7,6 мм для BZ1. Это размещение и схема соединений, **не готовая разводка PCB или Gerber**. Сборку сначала выполнить на стенде с ограничением тока и измерением полярности, затем проверить токи, нагрев, коммутационные выбросы и отсутствие сбоев контроллера. Никакой проверки реального электрического монтажа ещё не проводилось.

## Программа

Портативное ядро имеет состояния SAFE → DELAY → SEARCH. В SAFE кнопка TEST включает звук и свет максимум на 2 с за нажатие. В SEARCH два импульса по 0,2 с повторяются каждые 2 с; звуковой коэффициент заполнения 20%. Возврат INHIBIT на 2 с переводит в SAFE.

В энергонезависимой памяти хранятся признак взведения и контроль целостности. Запись выполняется при изменении состояния, а не в каждом цикле: [CircuitPython предупреждает](https://docs.circuitpython.org/en/stable/shared-bindings/nvm/index.html), что присваивание вызывает цикл стирания/записи. При старте с разомкнутой петлёй маяк сразу переходит к поиску, даже если запись повреждена; тихая задержка не запускается заново. Замкнутая петля при старте имеет приоритет.

Адаптер CircuitPython назначает выводы, читает кнопку/петлю, проверяет запись NVM и использует [watchdog](https://docs.circuitpython.org/en/stable/shared-bindings/watchdog/index.html). Он написан, но на выбранной плате не запускался. Особо проверить фактическое восстановление после watchdog и просадки питания на установленной версии CircuitPython: программная модель не доказывает поведение bootloader/safe mode и аппаратного стабилизатора.

## Размещение и акустический тракт

Кассета M01 находится под лотком, примерно X=944…1053 мм от вершины. Аккумулятор располагается в отдельном жёстком ложементе над платой, с пространством для мягких прокладок и провода. Прокладки, фиксация крышки и платы ещё требуют выбора и проверки. Затяжкой ленты нельзя деформировать ячейку. Блок управления спасением, основная батарея и самописец остаются отдельными узлами.

В кассете предусмотрены два звуковых окна. **Прохождение звука через окончательно собранный внешний корпус ещё не подтверждено.** Дополнительные отверстия в корпусе A04 не добавлялись: произвольный акустический порт изменит канал давления самописца. Сначала измерить звук через собранный корпус; при недостаточной слышимости разработать изолированный вывод звука и повторно проверить давление либо заменить миссию на GPS/радиопоиск. Для видимого снаружи LED нужен отдельный световод/окно; пока он является индикатором на модуле.

## Проверки и критерии следующего этапа

[Программные проверки](tests.csv), [временной ряд](trace.csv), [энергобаланс](energy.csv). Программный PASS не означает физическую реализацию или допуск к полёту.

| Проверка | Условия | Критерий проекта | Свидетельство |
|---|---|---|---|
| Электрическая независимость | Основной борт, его батарея и USB отсоединены | TEST, задержка и поиск работают от BT1 | Видеозапись и измерение напряжения; пока нет |
| Автономность | Полностью собранный модуль, режим поиска, выбранная температура | ≥6 ч от включения, без сбросов/опасного нагрева | Лог тока, напряжения, температуры; пока нет |
| Повторные включения | 20 циклов, в том числе в DELAY и SEARCH | При открытой петле восстановление звука; закрытая петля блокирует | Протокол стенда; пока нет |
| Звук сквозь корпус | 4 положения корпуса, фон и ветер зафиксированы | Сначала 10 м, затем целевые 25 м; наблюдатель не видит ракету | SPL/фон и время поиска; пока нет |
| Поиск в растительности | 10 скрытых размещений, одинаковая стартовая дистанция | Проектная цель: ≥9 находок за ≤5 мин каждая | Координаты размещений, видео и сырые результаты; пока нет |
| Посадка/удержание | Инертные макеты, нагрузки после уточнения полёта | Нет смещения, натяжения проводов и повреждений батареи | Нагрузки и метод ещё назначить |
| Влияние на основной борт | Запись IMU/давления с включённым и выключенным BZ1 | Сравнить помехи и пропуски данных до назначения допуска | Стенд ещё не собран |

Шесть часов и поисковые расстояния — критерии проекта; ТЗ не задаёт этих значений для звукового маяка. Зачёт миссии остаётся открытым до согласования варианта, изготовления и предъявления результатов.

## Энергобаланс стендового варианта

Токи пока назначены: контроллер 80 мА, звук 40 мА при включении и 20% заполнения, LED 3 мА при 30%. Средний ток от 3,3 В — 88,9 мА, мощность 0,29337 Вт; условный пик 123 мА. Эти значения нужно измерить на реальной плате.

Для 6 ч, КПД 0,85, доступной доли батареи 0,70 и запаса 1,25 требуется 0,29337 × 6 × 1,25 / (0,85 × 0,70) = **3,698 Вт·ч** паспортной энергии. Минимальная ёмкость TDS даёт 1,140 А·ч × 3,7 В = **4,218 Вт·ч**, что в той же модели соответствует **6,84 ч** с учётом запаса. Это сценарный запас, а не измеренная автономность; холод, порог отключения и фактический ток могут его изменить.

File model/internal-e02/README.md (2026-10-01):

# E02 · внутренняя компоновка и миссия M01

**Цифровой примерочный вариант от 01.10.2026.** 55 тел проверены; физические соединения и полётная пригодность не подтверждены. Внешняя геометрия A04 сохранена.

[3D с материалами и открытием кассеты](viewer.html) · [STEP](PLBP-SG1-E02.step) · [схема интерфейсов, 2 страницы](interfaces.pdf) · [детали и массы](parts.csv) · [полный реестр внутренних зон](internal_interfaces.csv) · [STL для примерки](fit-parts.zip).

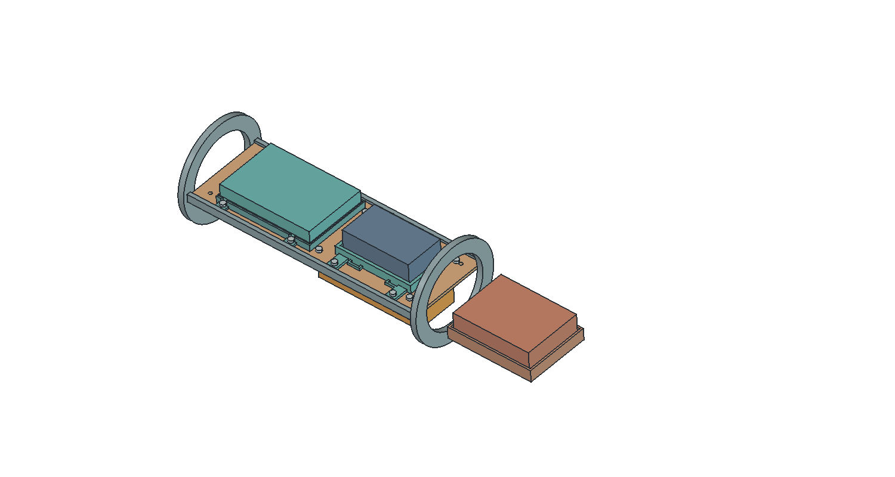
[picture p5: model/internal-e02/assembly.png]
Сборка E02


## Что уточнено

Основной борт получил собственный держатель и поднят над общим крепежом кассеты самописца. Под лотком размещён независимый звуковой модуль M01: корпус с внутренними акустическими окнами, отдельный ложемент батареи, опоры контроллера и платы ключа. Добавлен держатель габарита блока управления спасением. Разведены крепёж M01 и гайки держателя основной батареи.

Самописец проверен по максимальному габариту 85×31×19 мм. Батарея M01 — по чертежу изготовителя, 62,3×35,3×5,3 мм; ширина на странице магазина отличается от TDS. Проверен и увеличенный габарит звукового излучателя Ø12,6×10,7 мм. Детали и привязки приведены в PDF и CSV. Электроника показана габаритами, без утверждённой разводки PCB.

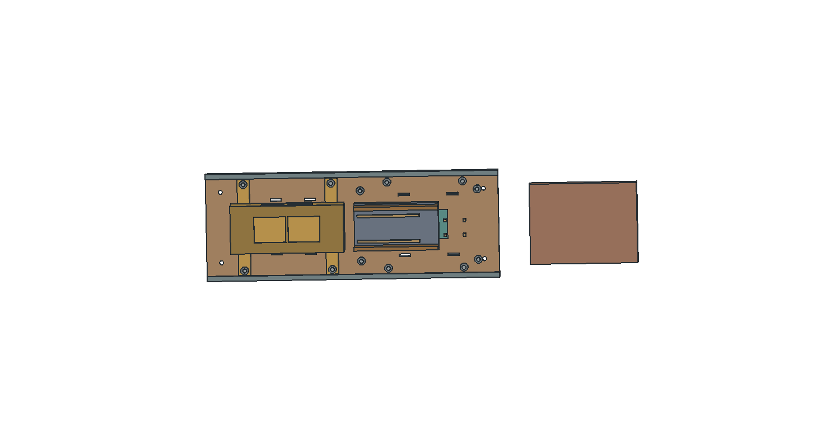
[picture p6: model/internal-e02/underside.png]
Обратная сторона с открытыми узлами


## Масса без двойного учёта

| Статья | г | Основание |
|---|---:|---|
| База A04 | 5787,092 | Прежняя расчётная ведомость, включая 120 г резерва |
| Удалены прежние лоток и опоры | −126.782 | Заменены новыми деталями |
| Новые неметаллические опоры и держатели E02 | +271.481 | Сплошная геометрия × назначенная плотность |
| Итого E02 | 5931.791 | Не взвешенная ракета |

Прирост к A04: **144.699 г**; к E01: **92,760 г**. Условный металлический крепёж 17.665 г выделен из прежнего 120-граммового резерва; остаток 102.335 г, а не новая добавка. Нельзя прибавлять его повторно.

M01 сохраняет прежние 80 г электроники и 40 г питания: контроллер 10 г (назначено), BZ1 1,6 г (каталог), плата ключа 4 г (назначено), остаток электроники 64,4 г; ячейка 23 г (каталог), остаток питания 17 г. Держатели добавлены отдельно. Блок спасения 150 г уже входил в A04. CSV геометрии содержит только показанные тела, поэтому его сумма не равна массе всей ракеты.

Материалы: PETG для примерочных держателей, 1,27 г/см³; условный стеклопластик лотка и опор 1,85 г/см³; условная сталь крепежа 7,85 г/см³. Это принятые плотности; свойства и допустимые напряжения лётного изделия не назначены. Фактическая масса печати, провода, прокладки и соединения требуют взвешивания.

## Полная карта внутренних зон

Реестр охватывает обтекатель и стык, полезную нагрузку, её упор, спасение, электронику, отдельный контроллер спасения и двигатель. Для каждой зоны указаны габарит, интерфейс и незакрытая проверка. **Подробно смоделированы держатели электроники; остальные зоны не объявлены готовыми узлами.**

Главные незакрытые интерфейсы: стык и извлечение лотка из корпуса, фиксация колец/опор, удержание полезной нагрузки, фалы и силовые точки спасения, крепление отдельного контроллера, удержание и тепловой режим двигателя. Мягкие прокладки, застёжки крышки M01, фиксация платы и жгуты пока не выпущены. Условные M3 не заменяют выбор реальных винтов, шайб и гаек.

## Проверки и следующий этап

Валидность 55 тел, отсутствие пересечений, размещение внутри Ø97 мм, максимальные габариты, STEP и замкнутость STL проверены автоматически. Нативный документ повторно открыт в GUI: материалы, плотности, видимость и MassAudit сохранены. Это проверка цифровой геометрии, без прочности и вибрации.

Сначала примерка реальных компонентов и прокладок; затем фиксация платы/крышки, проект корпусных соединений и обслуживания; далее стенд удержания и проверка давления. У M01 пока нет подтверждённого акустического и оптического пути через внешний корпус. Не добавлять порт в общий объём самописца без повторной проверки канала давления.

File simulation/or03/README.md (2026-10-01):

# OR03 · масса и центровка E02

Один новый тестовый случай OpenRocket 24.12. Он уточняет влияние новой внутренней компоновки; расчёт заканчивается на апогее. Сохранены A04/OR01 и E01/OR02. Совокупно 21 сохранённый случай, включая повторные базы; это не 21 независимое испытание.

[Модель E02](PLBP-SG1-E02-OR03.ork) · [временной ряд](e02.csv) · [итоги](summary.csv) · [инструкция и справочная кривая двигателя](../README.md).

| Показатель | Результат |
|---|---:|
| Стартовая масса | 5.931791 кг |
| Центр масс от вершины | 941.178 мм |
| Расчётный апогей над стартом | 1487.64 м |
| Максимальный скоростной напор q | 25.286 кПа |
| Скорость схода | 28.937 м/с |
| Максимальное число Маха | 0.607 |
| Минимальный запас при Vвозд ≥20 м/с | 2.353 D |

Условия: справочный K535W-REF, нагрузка 1500 г, направляющая 4 м, ISA у уровня моря, штиль, поверхность Normal 60 мкм, шаг 0,02 с, seed 20260930. Площадка, двигатель организаторов и реальные условия неизвестны. Внешняя геометрия A04 не менялась.

Ранее учтённые массы заменены деталями E02, электроника и питание дополнены остатками бюджетов; крепёж вычтен из прежнего резерва. Итог сверён с CAD. Масса, CG и повторный расчёт проверены после загрузки сохранённого ORK; разница апогея при том же seed 0.000000 м.

Ожидаемое предупреждение OpenRocket: отсутствует система спасения в расчётной модели. Спасение, отделение, спуск, посадка, флаттер и прочность здесь не рассчитаны. Звуковой поиск не проверяется этой симуляцией. Расчётная высота не является гарантией выполнения ТЗ.

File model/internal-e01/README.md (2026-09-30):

# E01 · примерочные крепления внутреннего оборудования

Геометрическая детализация A04: кассета самописца, держатель основной батареи, лоток с окнами и крепёж. **E01 — вариант для примерки; базовая ракета A04 ещё не заменена этим узлом.**

[STEP](PLBP-SG1-E01.step) · [интерактивный просмотр](viewer.html) · [схема интерфейсов PDF](interfaces.pdf) · [ведомость деталей](parts.csv) · [STL для примерки](fit-parts.zip).

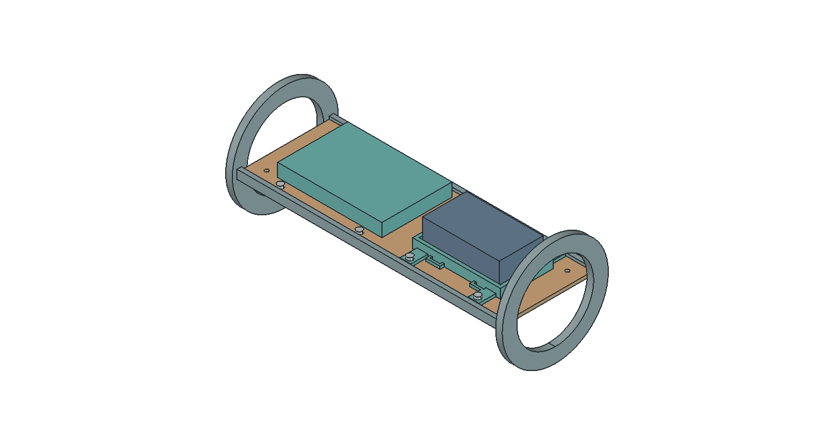
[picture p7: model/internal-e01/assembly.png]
Сборка E01


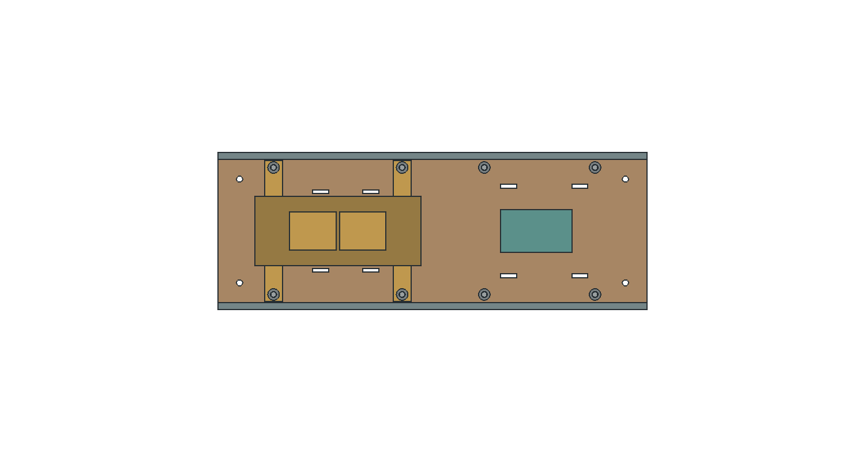
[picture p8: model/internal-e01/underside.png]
Вид со стороны самописца без габаритных блоков


## Размеры и интерфейсы

- Новый лоток: 240 × 80 × 3 мм; боковые опоры 240 × 4 × 8 мм. Окна уменьшают объём материала; механическая равноценность сплошному лотку пока не установлена.
- Самописец: полость 87 × 33 × 21 мм для максимального габарита 85 × 31 × 19 мм из номинала 84 × 30 × 18 ±1 мм. Прибор расположен около X=892 мм от носа; кассета оставляет номинально по 1 мм на сторону для максимального прибора. Допуск печати в этот запас ещё не включён.
- Кассета имеет боковые воздушные окна и решётчатую крышку; наружные 8×Ø1,6 мм A04 сохранены. Уложенная проводка, ленты и прокладки не должны перекрывать путь к реальному чувствительному элементу.
- Основная батарея: держатель под предварительный защищённый блок 70 × 40 × 22 мм, полость основания 74 × 42 мм, бортики 6 мм. Пазы лент в держателе и лотке согласованы. Батарея ещё не выбрана; держатель не предназначен для жёсткого сжатия незащищённой пакетной ячейки.
- Крепление держателей: по четыре M3; оси и номинальные отверстия приведены в PDF. Шляпки и гайки — упрощённые габариты, без резьбы, каталожной массы и подтверждённого затяжного усилия.

Ленты, мягкие прокладки, разъёмы и кабели не изображены как готовые узлы. Их артикулы, трассировку, фиксацию и испытания предстоит выполнить. Основной борт, поиск и их питание пока остаются габаритами; собственные крепления этих блоков ещё открыты.

## Масса без двойного учёта

Прежний лоток и две опоры: **126,78 г**. Новые неметаллические опоры, держатели и крышка: **178,72 г**. Прибавка к A04: **51,94 г**.

Условный крепёж по геометрии: 11,78 г. Он выделен из уже существующего 120-граммового резерва, а не прибавлен второй раз; нераспределённый остаток 108,22 г. Это пока бюджет для прочего крепежа, клея, кабелей, лент, прокладок и маркировки, не взвешенная комплектация.

С учётом E01 расчётная стартовая масса **5,839 кг**. В отдельном тесте OR02 апогей около 1505 м против 1514 м базы. Это проверка влияния массы; она не подтверждает удержание деталей в полёте.

## Материалы и проверки

PETG использован как кандидат для примерочных держателей, 1,27 г/см³ по [TDS производителя](https://storage.googleapis.com/prusa3d-content-prod-14e8-wordpress-prusament-prod/2023/10/9f8d2165-tds_prusament-petg_n_en.pdf). Масса считается для сплошной CAD-геометрии; реальная печать отличается. Паспортные свойства печатных образцов зависят от направления и режима, поэтому допускаемые напряжения для E01 не назначены. Лоток и опоры — условный стеклопластик 1,85 г/см³, как в A04; марка ламината ещё не выбрана. Для условного стального крепежа принята плотность 7,85 г/см³.

Проверены 29 отдельных валидных тел, отсутствие объёмных пересечений, радиальное размещение внутри Ø97 мм, максимальный габарит самописца, замкнутость сеток деталей, число тел и объём STEP. Нативный FreeCAD повторно открыт; видимость деталей проверена отдельно в GUI. Металлические тела здесь только условные крепёжные элементы.

**Проверка геометрии не заменяет испытания.** Не проверены прочность и ползучесть печати, удержание лентами, вибрация, соединение опор с лотком, фиксация лотка в корпусе и влияние температуры. В STL размеры в миллиметрах; это образцы для контроля посадки. Перед нагружением требуется проект соединений и технология, включая скругления кромок в местах лент/проводов.

## Обслуживание и следующая проверка

На извлечённом лотке батарея доступна сверху после снятия двух лент; самописец — снизу после снятия лент и крышки. **Способ извлечения лотка из собранной ракеты ещё не спроектирован.** Поэтому норматив замены батареи за пять минут не объявлен выполненным. Разъём корпуса и доступ к крепежу — приоритет следующей ревизии.

План примерки: проверить калибром 85×31×19 мм зазоры самописца и выход кабеля; собрать крепёж с реальными шайбами/гайками; проконтролировать зазоры до плат; проложить проводку с разгрузкой; убедиться, что батарея не нагружается через выводы. Затем измерить время обслуживания и провести стендовые проверки фиксации с инертными массовыми макетами по согласованным нагрузкам.

Для канала давления — сравнительная запись с эталонным датчиком при одинаковом изменении окружающего давления. Постоянные времени из [OR02](../../simulation/or02/README.md) являются исследовательскими допущениями. Защита самописца от воздействий соседних отсеков и наружных аэродинамических ошибок остаётся отдельной задачей; [руководство PerfectFlite, раздел установки](https://www.apogeerockets.com/downloads/PDFs/StratoLoggerCF_manual.pdf) используется как инженерная справка, а геометрию конкурсного самописца задаёт ТЗ ВИШ.

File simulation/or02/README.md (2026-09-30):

# OR02 · чувствительность полёта и измерений

15 новых расчётных случаев OpenRocket 24.12, включая повтор базы A04 и отдельный примерочный E01. Вместе с OR01 сохранены 20 случаев; повторная база не является независимым испытанием. **Все входы тестовые; расчёт до апогея.**

[Скачать модели, CSV и параметры одним архивом](OR02-models.zip) · [таблица CSV](summary.csv) · [базовая инструкция OpenRocket](../README.md).

Распаковать архив, импортировать `K535W-REF.rse` по базовой инструкции и открыть нужный `.ork`. Каждый файл содержит свой вариант массы/поверхности и одну симуляцию. Это предотвращает перенос изменённой массы на чужой сценарий. Остановка на апогее — штатный ApogeeEndListener; внешние плагины не нужны.

## Что изменяется

База: A04, нагрузка 1,5 кг, справочный K535W-REF, 4 м эффективного хода направляющей, ISA у уровня моря, 15 °C, ветер 0, Normal 60 мкм. Шаг 0,02 с; seed автоматической проверки 20260930.

- Температура: 0 и +35 °C при 101325 Па и высоте старта 0 м; используется расширенная ISA с заданными условиями у старта.
- Высота площадки: 500 м над уровнем моря; апогей в таблице отсчитывается от этой площадки. Это отдельный тест, не реальное место запуска.
- Поверхность: Smooth 20, Normal 60, Rough 500 мкм — параметры модели OpenRocket 24.12. Они не являются измеренным Ra нашего корпуса.
- Запас: дополнительные 150/300 г в X=950 мм. Облегчённый борт: 100 г вместо назначенных 180 г, без выбранного BOM. Это условное изменение, не подтверждённая экономия.
- Макет 1 кг: контроль расхождения сайта и PDF ВИШ; основной проект по-прежнему 1,5 кг.
- Профиль ветра: уровни 0/500/1500 м над уровнем моря, скорости 3/6/9 м/с. Во втором профиле направления 90/120/150° в соглашении OpenRocket. Между уровнями работает штатная интерполяция; за крайними уровнями — крайнее значение. Высота площадки в обоих профилях 0 м. Турбулентность 0: это сдвиг ветра, а не случайные порывы.
- Сочетание тяжёлых условий: 2 м направляющей, 6 м/с постоянного ветра, +300 г и Rough. Это выбранный стресс-сценарий, а не наихудшее возможное состояние и не статистический предел.
- E01: реальные массы новых внутренних деталей, замена старого лотка/опор и выделение крепежа из прежнего резерва. Массовая модель проверяется отдельно от готовности этих креплений к полёту.

## Результаты

| Случай | Старт, кг | Апогей, м | Δ к базе, м | max q, кПа | Сход, м/с |
|---|---:|---:|---:|---:|---:|
| База A04 | 5,787 | 1514 | 0,0 | 26,48 | 29,3 |
| Направляющая 2 м; ветер 6 м/с | 5,787 | 1484 | -30,7 | 26,56 | 21,1 |
| Старт на высоте 500 м | 5,787 | 1547 | 32,3 | 25,46 | 29,3 |
| Температура 0 °C | 5,787 | 1481 | -33,5 | 27,54 | 29,3 |
| Температура +35 °C | 5,787 | 1557 | 42,4 | 25,19 | 29,3 |
| Поверхность Smooth 20 мкм | 5,787 | 1586 | 71,3 | 27,01 | 29,3 |
| Поверхность Rough 500 мкм | 5,787 | 1357 | -157,4 | 25,14 | 29,3 |
| Дополнительные 150 г | 5,937 | 1487 | -27,6 | 25,24 | 28,9 |
| Дополнительные 300 г | 6,087 | 1458 | -55,9 | 24,08 | 28,5 |
| Контрольный макет 1 кг | 5,287 | 1600 | 86,2 | 31,16 | 31,0 |
| Борт 100 г вместо 180 г | 5,707 | 1529 | 14,5 | 27,17 | 29,8 |
| Ветер 3→6→9 м/с по высоте | 5,787 | 1505 | -9,5 | 26,53 | 29,3 |
| Ветер с поворотом по высоте | 5,787 | 1506 | -8,6 | 26,52 | 29,3 |
| Сочетание тяжёлых условий | 6,087 | 1286 | -228,5 | 23,04 | 20,3 |
| Внутренний модуль E01 — примерочный | 5,839 | 1505 | -9,5 | 26,04 | 29,1 |

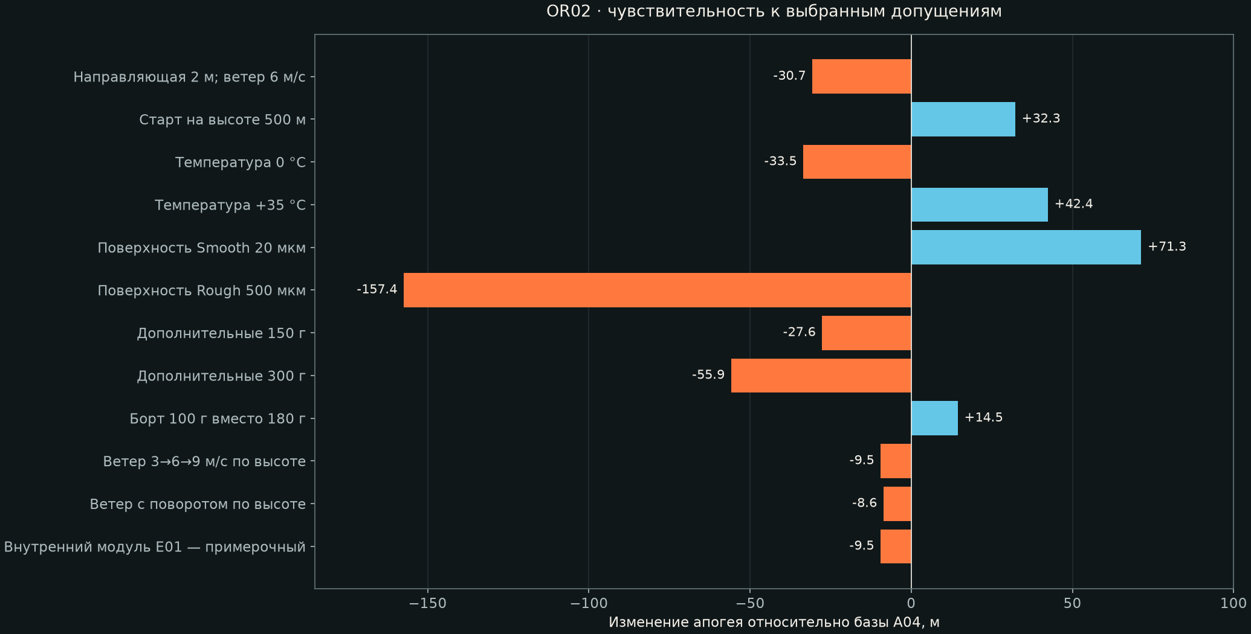
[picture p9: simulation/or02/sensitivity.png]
Чувствительность апогея


В выбранном диапазоне влияние поверхности больше, чем условная экономия 80 г на борте. Из этого не следует универсальный приоритет полировки: реальная шероховатость и Cd ещё не измерены. Уменьшение массы повышает также скорость и скоростной напор; его нельзя оценивать только по высоте.

У случая «2 м + ветер 6 м/с» минимум запаса после схода при Vвозд≥20 м/с — 1,296 D, максимальный угол атаки в этом интервале 15,9°. У комбинированного случая — 1,267 D и 16,4°. Эти числа отмечают чувствительные условия; они не доказывают допустимость пуска. Погрешность инженерной аэродинамической модели при таких углах может быть существенной.

## Условная задержка измерения давления

Отдельная модель первого порядка `dpдатчика/dt = (pвоздуха − pдатчика)/τ` наложена на атмосферное давление базовой траектории. Постоянные времени **0,02 / 0,1 / 0,5 с выбраны для сравнения**, а не рассчитаны по отверстиям и не измерены. Ошибка получена одинаковым ISA-преобразованием обоих давлений в высоту, поэтому сравнение выделяет именно задержку. Обработка сигнала прибора, шум и местные аэродинамические ошибки не учтены.

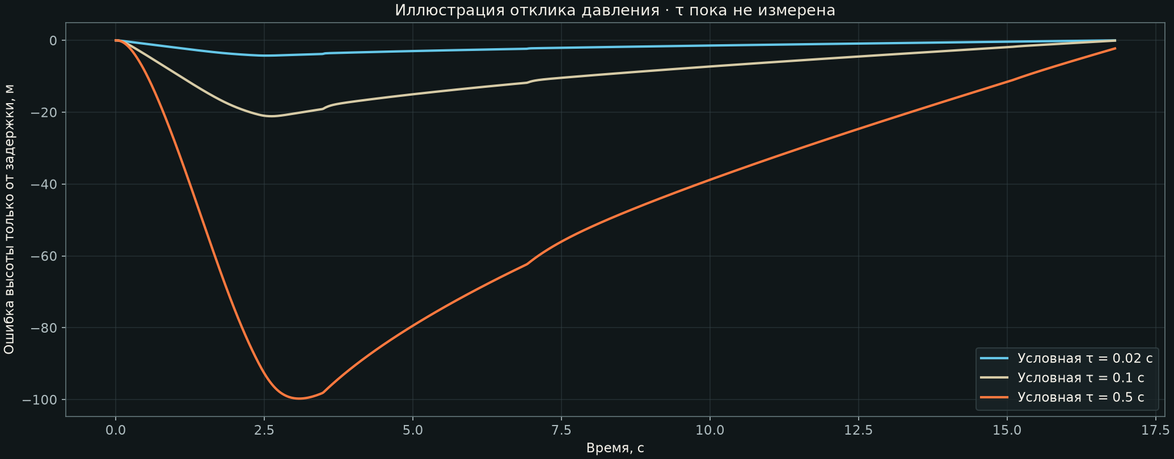
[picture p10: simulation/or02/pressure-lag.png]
Условная задержка давления


Максимальные ошибки для выбранных τ: 4,2 м, 21,1 м, 99,7 м. Эта модель объясняет необходимость стендового сравнения с эталонным датчиком; она не даёт рекомендацию менять восемь отверстий из ТЗ ВИШ.

## Проверки и ограничения

Все 15 `.ork` повторно загружены официальным ядром без предупреждений загрузчика. Проверены сохранённые массы, CG, профили ветра и временные ряды; пять репрезентативных случаев повторно рассчитаны, включая оба профиля ветра, сочетание условий и E01. При том же seed апогей воспроизвёлся. Кривая тяги и ограничения её оцифровки те же, что в OR01. Штатное предупреждение об отсутствии спасения ожидаемо и не скрыто.

Отделение макета, парашюты, посадка, флаттер и прочность не моделируются. Малый набор детерминированных сценариев не задаёт вероятность успеха или область гарантированных параметров. Seed в `.ork` 1.10 не сохраняется, поэтому повтор в GUI может немного отличаться. Полные условия — в `cases.json` внутри архива.

Источники: [масса и поверхность OpenRocket](https://openrocket.readthedocs.io/en/latest/user_guide/overrides_and_surface_finish.html), [шероховатость в коде 24.12](https://github.com/openrocket/openrocket/blob/release-24.12/core/src/main/java/info/openrocket/core/rocketcomponent/ExternalComponent.java), [многоуровневый ветер 24.12](https://github.com/openrocket/openrocket/blob/release-24.12/core/src/main/java/info/openrocket/core/models/wind/MultiLevelPinkNoiseWindModel.java).

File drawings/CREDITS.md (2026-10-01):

# Исходная CAD-геометрия производителя

Feather RP2040 #4884: [Adafruit CAD Parts](https://github.com/adafruit/Adafruit_CAD_Parts/tree/6f52ee4d48df0e7118d2d82f485cb572051a24fe/4884%20Feather%20RP2040). Commit `6f52ee4d48df0e7118d2d82f485cb572051a24fe`; исходный STEP SHA-256 `de85fb7f6644cdea17808208d888e64264d691573da8cd0fee808e2fd44d477f`. Геометрия перенесена жёстким перемещением без масштабирования. Цвета для просмотра назначены проектом. Масса платы 10 г остаётся проектной оценкой; STEP сам по себе не является паспортом массы.

Лицензия производителя MIT воспроизведена ниже и относится к заимствованной геометрии.

```text
MIT License

Copyright (c) 2016 Adafruit Industries

Permission is hereby granted, free of charge, to any person obtaining a copy
of this software and associated documentation files (the "Software"), to deal
in the Software without restriction, including without limitation the rights
to use, copy, modify, merge, publish, distribute, sublicense, and/or sell
copies of the Software, and to permit persons to whom the Software is
furnished to do so, subject to the following conditions:

The above copyright notice and this permission notice shall be included in all
copies or substantial portions of the Software.

THE SOFTWARE IS PROVIDED "AS IS", WITHOUT WARRANTY OF ANY KIND, EXPRESS OR
IMPLIED, INCLUDING BUT NOT LIMITED TO THE WARRANTIES OF MERCHANTABILITY,
FITNESS FOR A PARTICULAR PURPOSE AND NONINFRINGEMENT. IN NO EVENT SHALL THE
AUTHORS OR COPYRIGHT HOLDERS BE LIABLE FOR ANY CLAIM, DAMAGES OR OTHER
LIABILITY, WHETHER IN AN ACTION OF CONTRACT, TORT OR OTHERWISE, ARISING FROM,
OUT OF OR IN CONNECTION WITH THE SOFTWARE OR THE USE OR OTHER DEALINGS IN THE
SOFTWARE.

```

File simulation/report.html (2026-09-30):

PLBP–SG1 / A04 · OR01 / OPENROCKET 24.12

# Полёт. Центровка. Давление.

Пять тестовых сценариев для команды. Геометрия из CAD, полезная нагрузка 1,5 кг. Результаты рассчитаны ядром OpenRocket; площадка, направляющая и конкурсный двигатель пока неизвестны.

Расчёт до апогея, включая возможные несколько шагов обнаружения события. Отделение макета, раскрытие парашютов и посадка не моделируются.

Исходные допущения и инструкция OpenRocket · Скачать .ork

Тестовый сценарийМомент полёта: 0,00 с

## Подъём

Высота над стартом, м

## Центровка

Центр масс CG, ммЦентр давления CP, мм

Координаты от вершины носа. CP показан при Vвозд ≥20 м/с; при больших углах атаки применимость оценки ограничена.

## Давление и напор

Скоростной напор q, кПаАтмосферное p, кПа

q = ½ρVвозд². Скорость относительно воздуха, с учётом ветра.

## Скорость относительно воздуха

Vвозд, м/с

У земли ветер создаёт относительный поток даже до движения ракеты.

## Сопоставление сценариев

Тест | Апогей, м | max q, кПа | Сход, м/с | Смещение у апогея, м

Смещение у апогея не является точкой посадки. Ветер 6 м/с — исследуемое допущение, не разрешённый предел запуска.

## Что такое CG и CP

CG — центр массы: сумма mᵢxᵢ, делённая на общую массу. На старте он находится в 940,3 мм от носа, после выгорания — в 873,7 мм. Тяжёлая хвостовая часть теряет массу, CG смещается вперёд.

CP — расчётная точка приложения результирующей нормальной аэродинамической силы. Она меняется с числом Маха и углом атаки. Запас устойчивости: (CP − CG) / 100 мм. Положительный запас — один из показателей; он не доказывает отсутствие флаттера или устойчивость во всех условиях.

## Как понимать давление

Атмосферное давление p уменьшается с высотой. Для нагрузки на замкнутую оболочку важна разность давлений снаружи и внутри; внутреннее давление здесь не рассчитывается.

Скоростной напор q задаёт масштаб аэродинамических нагрузок. Местное давление на поверхности зависит от распределения коэффициента давления. График q не является картой давлений, расчётом напряжений или доказательством прочности стабилизаторов.

Проверено численно: совпадение массы и продольного CG с CAD, загрузка .ork с двигателем из прилагаемого .rse, повторный расчёт пяти сценариев и чувствительность к шагу 0,02 → 0,01 с. Не проверено физически: массы и инерция сборки, аэродинамика, двигатель организаторов, соединения, спасение и отделение.

Автономный отчёт. Данные встроены; интернет для графиков не нужен. Полные выборки — в отдельных CSV. Небольшие изменения повторного расчёта в GUI возможны: OpenRocket 24.12 не сохраняет seed случайных малых моментов в .ork. Источники и точные допущения — в README.

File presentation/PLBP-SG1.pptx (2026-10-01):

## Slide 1

ПРЕДВАРИТЕЛЬНОЕ ПРОЕКТИРОВАНИЕ / A04

PLBP / SG1

PLBP–SG1

Ракета для лиги «Супер ГИРД»

SG / 01

1,5 кг полезной нагрузки. Проверяемый цифровой проект.

Ревизия A04 · 30 сентября 2026 · цифровой прототип

01 / 25

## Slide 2

01 / РЕЗУЛЬТАТЫ ПРОЕКТА

Три результата одного полёта

PLBP / SG1

≥ 1 км

Выведение макета

Порог из опубликованного ТЗ XV сезона.

Возврат

Носитель и макет

Отдельная проверка каждой системы спасения.

Данные

Борт + земля

Измерения, события и сопоставление журналов.

Конкурсная база: XV сезон 2025–2026. Условия нового сезона предстоит подтвердить.

02 / 25

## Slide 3

02 / РЕЗУЛЬТАТЫ ПРОЕКТА

Макет — это полезная нагрузка

PLBP / SG1

1,5 кг

Основной проектный вариант по странице чемпионата ВИШ.

1,0 кг

В опубликованном PDF XV: Ø84×220 вместе с парашютом.

Без лимита

Масса самой ракеты не ограничена: ТЗ, п. 1.1.1.

Расхождение источников открыто. Габарит макета 1,5 кг требует подтверждения.

03 / 25

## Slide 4

03 / РЕЗУЛЬТАТЫ ПРОЕКТА

PLBP / SG1

Первая параметрическая ракета

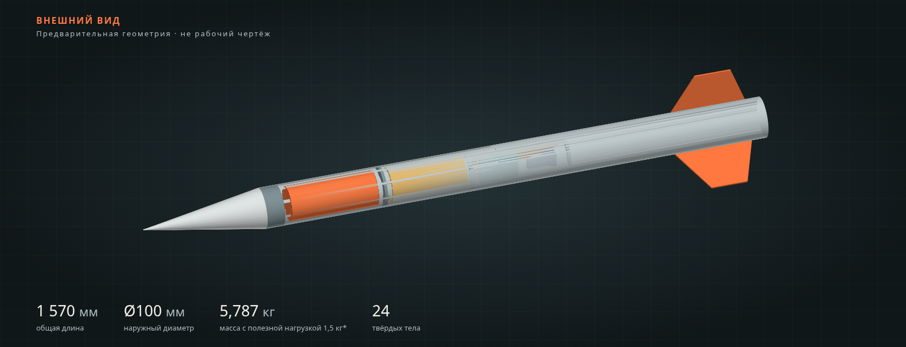
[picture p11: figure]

FreeCAD A04 · длина 1,57 м · корпус Ø100 мм · три неподвижных стабилизатора.

04 / 25

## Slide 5

04 / РЕЗУЛЬТАТЫ ПРОЕКТА

PLBP / SG1

Внутренние объёмы уже размещены

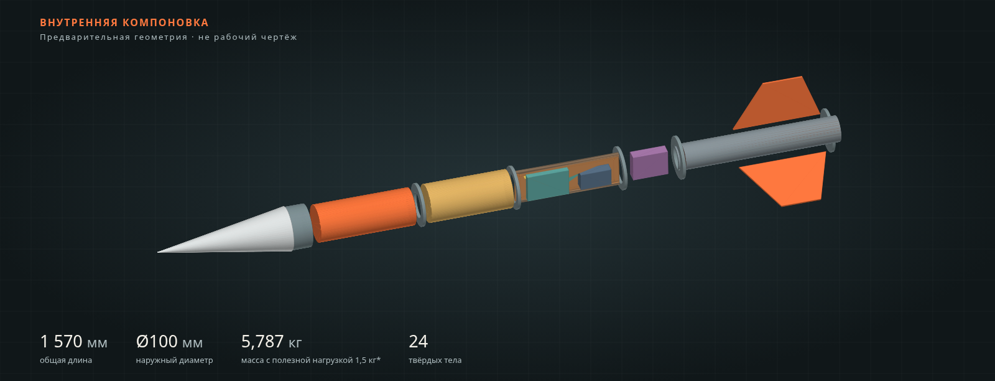
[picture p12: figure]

Корпус скрыт для просмотра. Электроника и парашют представлены условными габаритами.

05 / 25

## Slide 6

05 / РЕЗУЛЬТАТЫ ПРОЕКТА

PLBP / SG1

Размеры и интерфейсы зафиксированы

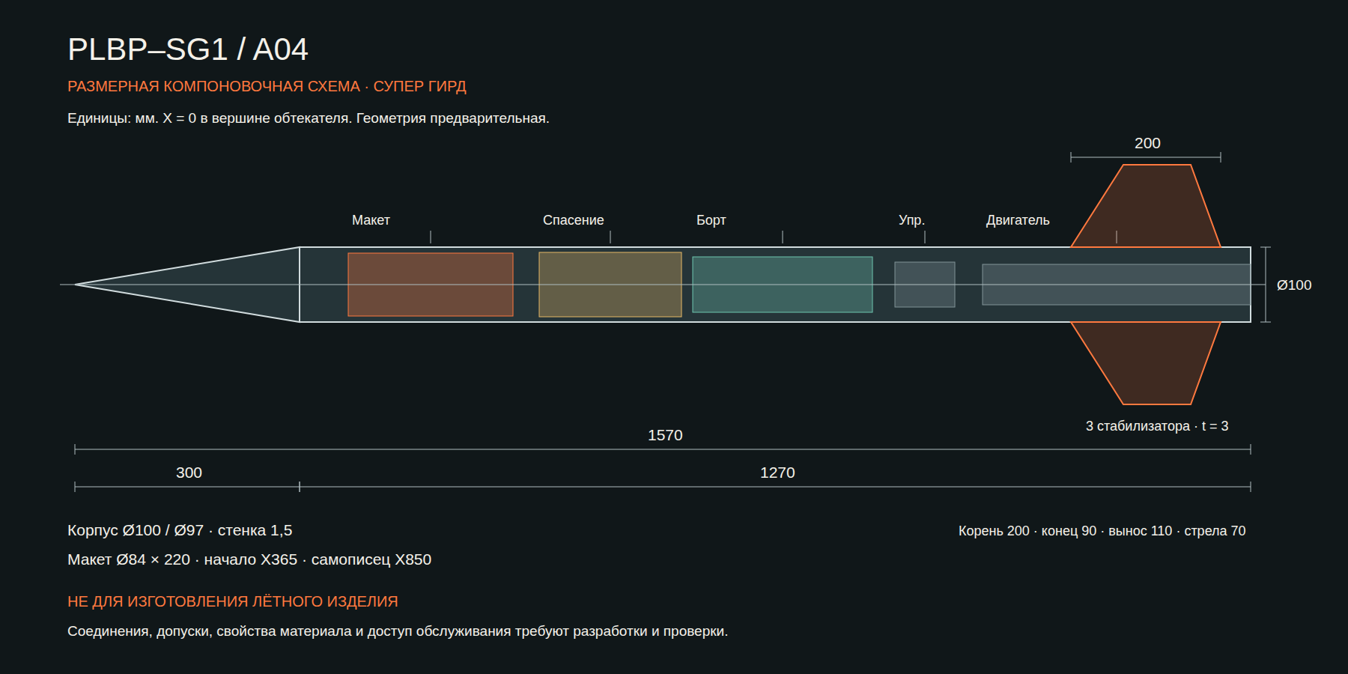
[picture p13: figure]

Компоновочная схема A04. Рабочие чертежи с допусками и силовыми соединениями ещё не выпущены.

06 / 25

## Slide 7

06 / РЕЗУЛЬТАТЫ ПРОЕКТА

Центровка с нагрузкой 1,5 кг

PLBP / SG1

CG: 940 мм

Центр массы старта от вершины.

CP: 1169 мм

OpenRocket: M=0,05; угол атаки 0°.

Запас: 2,285 D

Статическая оценка; флаттер не проверен.

CP зависит от скорости и угла атаки. Ручная низкоскоростная оценка: 1169 мм.

07 / 25

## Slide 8

07 / РЕЗУЛЬТАТЫ ПРОЕКТА

PLBP / SG1

1D: влияние принятого Cd

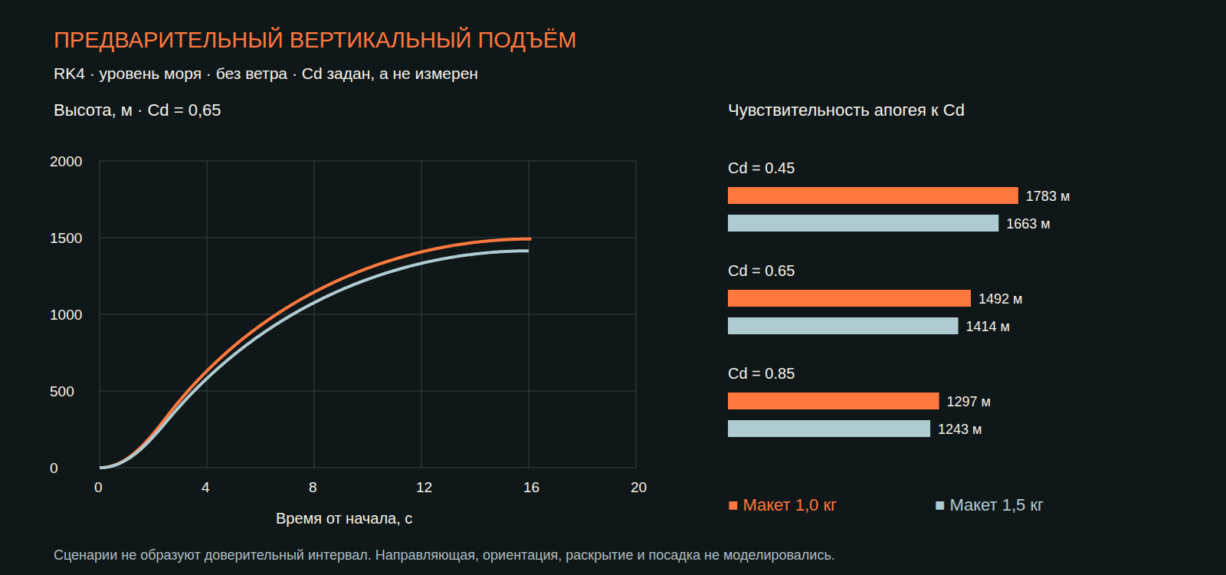
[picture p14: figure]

Основной макет 1,5 кг: 1,24–1,66 км при трёх принятых Cd. Это расчётная оценка.

08 / 25

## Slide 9

OPENROCKET / OR01

PLBP / SG1

OpenRocket: пять тестовых сценариев


Штиль: 1514 м. Ветер и направляющая — тестовые; расчёт заканчивается у апогея.

09 / 25

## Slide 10

OPENROCKET / OR01

PLBP / SG1

Центровка и давление в полёте


CG: 940 → 874 мм. Max q: 26,48 кПа. Карта давлений и прочность ещё не рассчитаны.

10 / 25

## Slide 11

OPENROCKET / OR01

Модель можно открыть и пересчитать

PLBP / SG1

.ork + .rse

OpenRocket 24.12. Пять сохранённых сценариев, штатная остановка на апогее.

Проверка переноса

Масса и CG совпали с CAD. Проверены повторная загрузка и уменьшение шага.

Следующий шаг

Реальные массы, двигатель, ветер, направляющая; разработка отделения и спасения.

Шестистепенная модель жёсткого тела. Расчётная воспроизводимость не равна подтверждению полётом.

11 / 25

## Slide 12

08 / РЕЗУЛЬТАТЫ ПРОЕКТА

Модульная конструкция

PLBP / SG1

Учебный макет

Собственная система спасения.

Возврат носителя

Спасение и обслуживаемые крепления.

01

02

Бортовая система

Измерения, запись, радио, самописец.

Двигательный модуль

Справочный интерфейс Ø54 × 358 мм.

03

04

A04: последовательность отсеков задана. Крепления, разделение и обслуживание требуют разработки.

12 / 25

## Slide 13

09 / РЕЗУЛЬТАТЫ ПРОЕКТА

Масса базовой компоновки A04

PLBP / SG1

5,287 кг

Контрольный макет 1,0 кг — PDF ТЗ

Полная стартовая масса; лимит по ТЗ не установлен.

Основной макет 1,5 кг — проект

Полная стартовая масса; лимит по ТЗ не установлен.

5,787 кг

Историческая база. Текущий вариант E02: 5,932 кг с полезной нагрузкой 1,5 кг.

13 / 25

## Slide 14

10 / РЕЗУЛЬТАТЫ ПРОЕКТА

Материалы и честное облегчение

PLBP / SG1

Стеклопластик

1850 кг/м³ — принятая плотность. Марка и укладка открыты.

Полимер

1270 кг/м³ — допущение для обтекателя.

−630 г условно

Варианты стенок, материала и плат; без проверки не применены.

MassAudit и просмотрщик раскрывают каждую массу. Подтверждённая экономия без потерь: 0 г.

14 / 25

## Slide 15

11 / РЕЗУЛЬТАТЫ ПРОЕКТА

Что подтверждено на этой итерации

PLBP / SG1

Сделано

CAD A04, материалы, STEP и просмотр.
GUI, ведомость и предварительные расчёты.

Открыто

Рабочие соединения и компоненты.
Прочность, стенды и полёт.

24 тела; стабилизаторы видны после повторного открытия в FreeCAD. Физических испытаний нет.

15 / 25

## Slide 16

OR02 / E01 · ИССЛЕДОВАНИЕ

PLBP / SG1

Что влияет на расчётную высоту


OR02: 15 тестовых случаев, включая базу. Диапазоны допущений не являются вероятностными границами.

16 / 25

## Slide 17

OR02 / E01 · ИССЛЕДОВАНИЕ

PLBP / SG1

Предыдущий вариант E01


Прибавка к A04: 51,9 г. Проверены геометрия и зазоры; прочность и удержание ещё не испытаны.

17 / 25

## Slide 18

OR02 / E01 · ИССЛЕДОВАНИЕ

PLBP / SG1

Самописец: защита и воздух


Полость 87×33×21 мм; максимальный прибор 85×31×19 мм. Ленты, прокладки и проводка ещё не выбраны.

18 / 25

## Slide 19

OR02 / E01 · ИССЛЕДОВАНИЕ

PLBP / SG1

Измерению давления нужен стенд


τ = 0,02 / 0,1 / 0,5 с — допущения для сравнения, не измеренные характеристики самописца.

19 / 25

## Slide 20

OR02 / E01 · ИССЛЕДОВАНИЕ

Следующие узлы определены

PLBP / SG1

Обслуживание

Спроектировать стыки корпуса и доступ к лотку.

Удержание

Закрыть крепления платы, батарей и блока спасения; затем стенд.

Данные запуска

Получить двигатель организаторов, реальные массы, ветер и направляющую.

Текущая компоновка E02 и миссия M01 показаны далее; испытания остаются отдельным этапом.

20 / 25

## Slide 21

E02 / M01 / OR03 · 01.10.2026

PLBP / SG1

Внутренние узлы E02


55 тел без пересечений. Материалы и массы сохранены. Соединения и прочность требуют испытаний.

21 / 25

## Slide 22

E02 / M01 / OR03 · 01.10.2026

PLBP / SG1

Миссия M01: независимый поиск

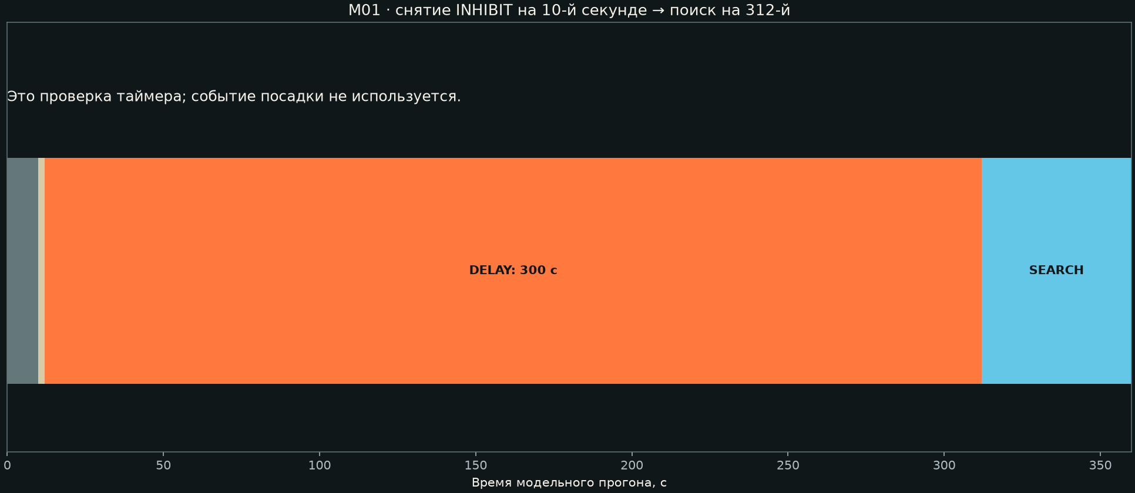
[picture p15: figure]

Собственная батарея. Посадка не определяется; поиск начинается по таймеру. Программа прошла 17 проверок.

22 / 25

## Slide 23

E02 / M01 / OR03 · 01.10.2026

M01: от программы к стенду

PLBP / SG1

Цель миссии

Звук для ближнего поиска. Проверить 10 м, затем целевые 25 м.

Питание

LiPo 1200 мА·ч. Цель — 6 ч от включения; токи расчётные.

Открытая проверка

Звук через корпус, помехи самописцу и критерий зачёта.

RP2040, излучатель и отдельная кассета. Аппаратных испытаний ещё нет.

23 / 25

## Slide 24

E02 / M01 / OR03 · 01.10.2026

E02 в расчёте OpenRocket

PLBP / SG1

5,932

кг на старте

Макет 1,5 кг; +144,7 г к A04.

1488

м над стартом

Тестовый K535W, штиль, направляющая 4 м.

25,286

кПа / max q

Расчёт до апогея; без спасения и посадки.

OR03: масса и CG сверены с CAD, сохранённая модель повторно открыта и пересчитана. Физической валидации нет.

24 / 25

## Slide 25

ИСТОЧНИКИ

Основания и допущения

PLBP / SG1

ВИШ

Полное положение и приложения 1–7; ТЗ СГ.

https://aesa.tech/documentation

AeroTech

Размеры, масса и график справочного двигателя.

https://aerotech-rocketry.com/pages/catalogs-brochures

NASA / Barrowman

Метод линейной оценки и ограничения применимости.

https://ntrs.nasa.gov/citations/20010047838

Официальные документы ВИШ и источники расчётных данных. Проверено 30.09.2026.

25 / 25

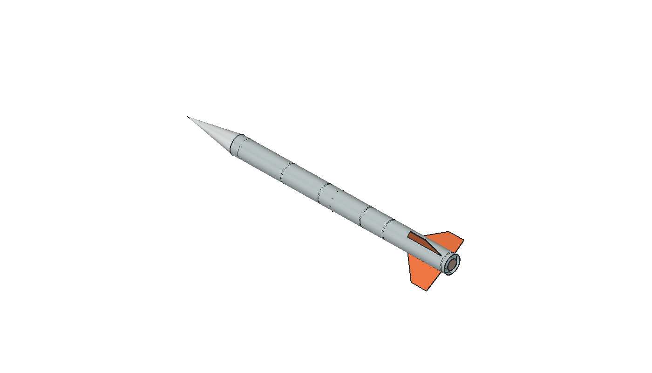
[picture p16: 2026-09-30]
assets/rocket.png

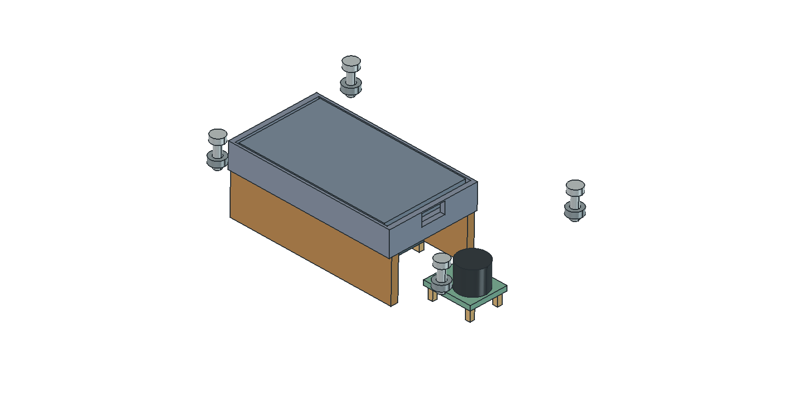
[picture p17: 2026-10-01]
model/internal-e02/mission.png

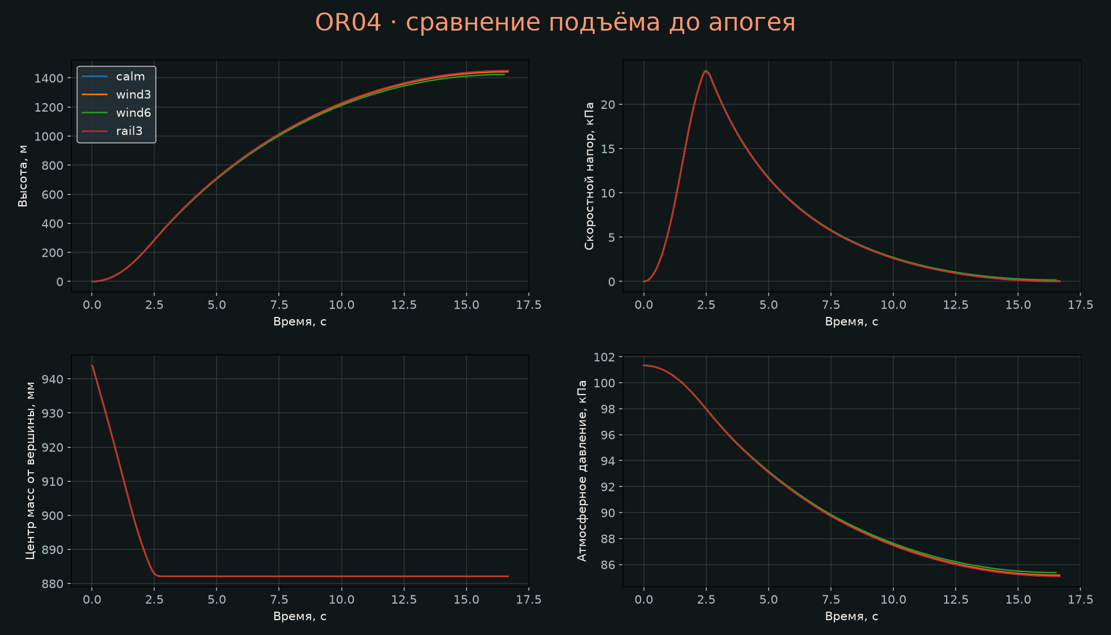
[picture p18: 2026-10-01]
simulation/or04/comparison.png

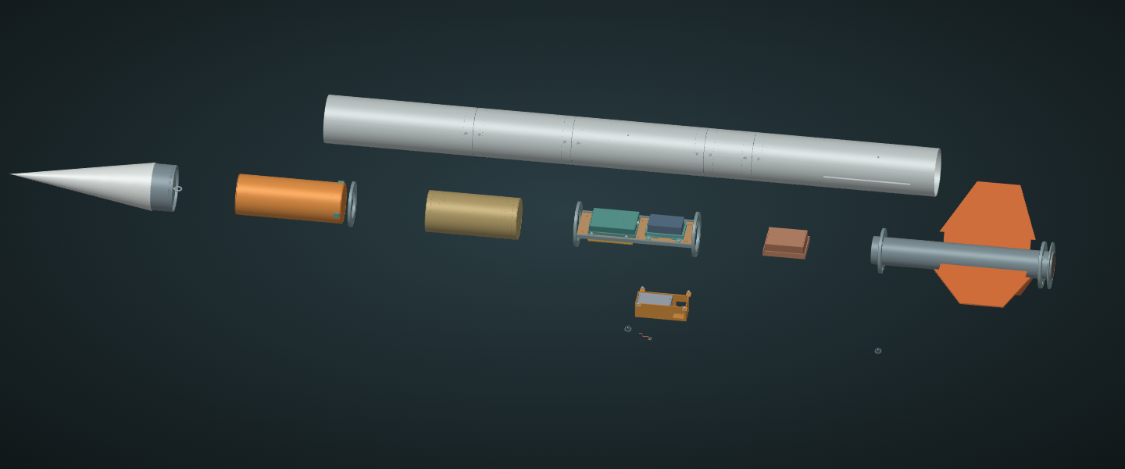
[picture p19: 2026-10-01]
model/full-d01/exploded-canvas.png

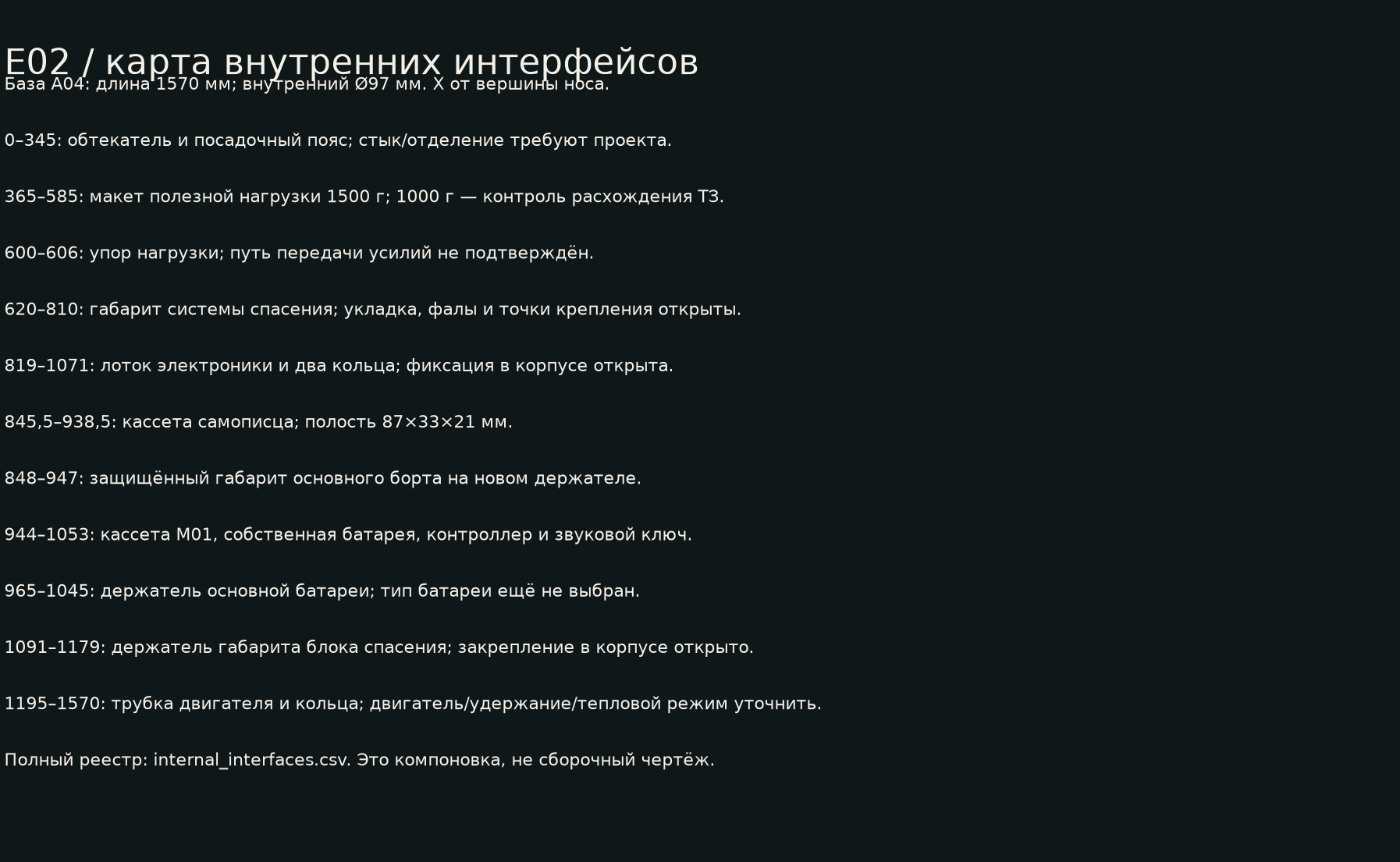
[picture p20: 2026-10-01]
model/internal-e02/layout.png

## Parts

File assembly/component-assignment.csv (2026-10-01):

position | drawing_id | name | label | assembly_step | quantity | status
1 | PLBP-D01-P001 | GuideRail0 | E01 боковая опора 1 | A50 | 1 | PLANNED_NOT_EXECUTED
2 | PLBP-D01-P002 | GuideRail1 | E01 боковая опора 2 | A50 | 1 | PLANNED_NOT_EXECUTED
3 | PLBP-D01-P003 | LoggerMount3 | Кассета самописца: открытые каналы давления | A50 | 1 | PLANNED_NOT_EXECUTED
4 | PLBP-D01-P004 | LoggerLidWindow1 | Решётчатая крышка самописца: фиксация двумя лентами | A50 | 1 | PLANNED_NOT_EXECUTED
5 | PLBP-D01-P005 | BatteryStrapSlot3 | Держатель основной батареи: бортики, вывод провода, две ленты | A50 | 1 | PLANNED_NOT_EXECUTED
6 | PLBP-D01-P006 | LoggerBolt0 | Logger M3×10: условный крепёж 1 | A50 | 1 | PLANNED_NOT_EXECUTED
7 | PLBP-D01-P007 | LoggerNut0 | Logger гайка M3: цилиндрический габарит 1 | A50 | 1 | PLANNED_NOT_EXECUTED
8 | PLBP-D01-P008 | LoggerBolt1 | Logger M3×10: условный крепёж 2 | A50 | 1 | PLANNED_NOT_EXECUTED
9 | PLBP-D01-P009 | LoggerNut1 | Logger гайка M3: цилиндрический габарит 2 | A50 | 1 | PLANNED_NOT_EXECUTED
10 | PLBP-D01-P010 | LoggerBolt2 | Logger M3×10: условный крепёж 3 | A50 | 1 | PLANNED_NOT_EXECUTED
11 | PLBP-D01-P011 | LoggerNut2 | Logger гайка M3: цилиндрический габарит 3 | A50 | 1 | PLANNED_NOT_EXECUTED
12 | PLBP-D01-P012 | LoggerBolt3 | Logger M3×10: условный крепёж 4 | A50 | 1 | PLANNED_NOT_EXECUTED
13 | PLBP-D01-P013 | LoggerNut3 | Logger гайка M3: цилиндрический габарит 4 | A50 | 1 | PLANNED_NOT_EXECUTED
14 | PLBP-D01-P014 | BatteryBolt0 | Battery M3×10: условный крепёж 1 | A50 | 1 | PLANNED_NOT_EXECUTED
15 | PLBP-D01-P015 | BatteryNut0 | Battery гайка M3: цилиндрический габарит 1 | A50 | 1 | PLANNED_NOT_EXECUTED
16 | PLBP-D01-P016 | BatteryBolt1 | Battery M3×10: условный крепёж 2 | A50 | 1 | PLANNED_NOT_EXECUTED
17 | PLBP-D01-P017 | BatteryNut1 | Battery гайка M3: цилиндрический габарит 2 | A50 | 1 | PLANNED_NOT_EXECUTED
18 | PLBP-D01-P018 | BatteryBolt2 | Battery M3×10: условный крепёж 3 | A50 | 1 | PLANNED_NOT_EXECUTED
19 | PLBP-D01-P019 | BatteryNut2 | Battery гайка M3: цилиндрический габарит 3 | A50 | 1 | PLANNED_NOT_EXECUTED
20 | PLBP-D01-P020 | BatteryBolt3 | Battery M3×10: условный крепёж 4 | A50 | 1 | PLANNED_NOT_EXECUTED
21 | PLBP-D01-P021 | BatteryNut3 | Battery гайка M3: цилиндрический габарит 4 | A50 | 1 | PLANNED_NOT_EXECUTED
22 | PLBP-D01-P022 | Logger | Самописец организатора · габарит A04 | A50 | 1 | PLANNED_NOT_EXECUTED
23 | PLBP-D01-P023 | MainPower | Основное питание · габарит A04 | A50 | 1 | PLANNED_NOT_EXECUTED
24 | PLBP-D01-P024 | MainHeadClearance3 | E02 опора основного блока: общий крепёж с кассетой самописца | A50 | 1 | PLANNED_NOT_EXECUTED
25 | PLBP-D01-P025 | BeaconMount3 | M01 несущая кассета: электроника, питание, звуковые окна | A60 | 1 | PLANNED_NOT_EXECUTED
26 | PLBP-D01-P026 | M01BatteryTray | M01 ложемент батареи: жёсткая защита без обжатия ячейки | A60 | 1 | PLANNED_NOT_EXECUTED
27 | PLBP-D01-P027 | M01BatteryCover | M01 защитная крышка батареи: зазор 1 мм | A60 | 1 | PLANNED_NOT_EXECUTED
28 | PLBP-D01-P028 | M01ShelfSupport0 | M01 продольная опора полки 1 | A60 | 1 | PLANNED_NOT_EXECUTED
29 | PLBP-D01-P029 | M01ShelfSupport1 | M01 продольная опора полки 2 | A60 | 1 | PLANNED_NOT_EXECUTED
30 | PLBP-D01-P030 | M01BoardSupport0 | M01 примерочная опора платы 1 | A60 | 1 | PLANNED_NOT_EXECUTED
31 | PLBP-D01-P031 | M01BoardSupport1 | M01 примерочная опора платы 2 | A60 | 1 | PLANNED_NOT_EXECUTED
32 | PLBP-D01-P032 | M01Battery | M01 LiPo #258 · максимальный габарит TDS с PCM | A60 | 1 | PLANNED_NOT_EXECUTED
33 | PLBP-D01-P033 | M01Buzzer | M01 CMI-1295-85T · звуковой индикатор | A60 | 1 | PLANNED_NOT_EXECUTED
34 | PLBP-D01-P034 | M01BuzzerLead0 | M01 вывод индикатора: масса входит в 1,6 г | A60 | 1 | PLANNED_NOT_EXECUTED
35 | PLBP-D01-P035 | M01BuzzerLead1 | M01 вывод индикатора: масса входит в 1,6 г | A60 | 1 | PLANNED_NOT_EXECUTED
36 | PLBP-D01-P036 | M01DriverHole1 | M01 плата ключа и диода · отверстия индикатора с шагом 7,6 мм | A60 | 1 | PLANNED_NOT_EXECUTED
37 | PLBP-D01-P037 | M01DriverSupport0 | M01 опора платы ключа 1 | A60 | 1 | PLANNED_NOT_EXECUTED
38 | PLBP-D01-P038 | M01DriverSupport1 | M01 опора платы ключа 2 | A60 | 1 | PLANNED_NOT_EXECUTED
39 | PLBP-D01-P039 | M01DriverSupport2 | M01 опора платы ключа 3 | A60 | 1 | PLANNED_NOT_EXECUTED
40 | PLBP-D01-P040 | M01DriverSupport3 | M01 опора платы ключа 4 | A60 | 1 | PLANNED_NOT_EXECUTED
41 | PLBP-D01-P041 | E02DeckHole3 | E02 лоток с креплением автономной кассеты | A50 | 1 | PLANNED_NOT_EXECUTED
42 | PLBP-D01-P042 | M01Bolt0 | M01 M3×10 · условный крепёж 1 | A60 | 1 | PLANNED_NOT_EXECUTED
43 | PLBP-D01-P043 | M01Nut0 | M01 гайка M3 · габарит 1 | A60 | 1 | PLANNED_NOT_EXECUTED
44 | PLBP-D01-P044 | M01Bolt1 | M01 M3×10 · условный крепёж 2 | A60 | 1 | PLANNED_NOT_EXECUTED
45 | PLBP-D01-P045 | M01Nut1 | M01 гайка M3 · габарит 2 | A60 | 1 | PLANNED_NOT_EXECUTED
46 | PLBP-D01-P046 | M01Bolt2 | M01 M3×10 · условный крепёж 3 | A60 | 1 | PLANNED_NOT_EXECUTED
47 | PLBP-D01-P047 | M01Nut2 | M01 гайка M3 · габарит 3 | A60 | 1 | PLANNED_NOT_EXECUTED
48 | PLBP-D01-P048 | M01Bolt3 | M01 M3×10 · условный крепёж 4 | A60 | 1 | PLANNED_NOT_EXECUTED
49 | PLBP-D01-P049 | M01Nut3 | M01 гайка M3 · габарит 4 | A60 | 1 | PLANNED_NOT_EXECUTED
50 | PLBP-D01-P050 | RecoveryCarrier | E02 примерочная опора блока спасения: крепление к корпусу открыто | A70 | 1 | PLANNED_NOT_EXECUTED
51 | PLBP-D01-P051 | BodyFix0_610_2 | Корпус · секция payload | A90 | 1 | PLANNED_NOT_EXECUTED
52 | PLBP-D01-P052 | BodyFix1_815_2 | Корпус · секция recovery | A90 | 1 | PLANNED_NOT_EXECUTED
53 | PLBP-D01-P053 | GuideBodyHole930 | Корпус · секция avionics | A90 | 1 | PLANNED_NOT_EXECUTED
54 | PLBP-D01-P054 | BodyFix3_1190_2 | Корпус · секция control | A90 | 1 | PLANNED_NOT_EXECUTED
55 | PLBP-D01-P055 | GuideBodyHole1450 | Корпус · секция motor | A90 | 1 | PLANNED_NOT_EXECUTED
56 | PLBP-D01-P056 | JointScrew610_596_0SocketCut | Стык 610 · M3, условная длина | A90 | 1 | PLANNED_NOT_EXECUTED
57 | PLBP-D01-P057 | JointNut610_596_0 | Стык 610 · закладная гайка, фиксация требует разработки | A90 | 1 | PLANNED_NOT_EXECUTED
58 | PLBP-D01-P058 | JointScrew610_596_1SocketCut | Стык 610 · M3, условная длина | A90 | 1 | PLANNED_NOT_EXECUTED
59 | PLBP-D01-P059 | JointNut610_596_1 | Стык 610 · закладная гайка, фиксация требует разработки | A90 | 1 | PLANNED_NOT_EXECUTED
60 | PLBP-D01-P060 | JointScrew610_596_2SocketCut | Стык 610 · M3, условная длина | A90 | 1 | PLANNED_NOT_EXECUTED
61 | PLBP-D01-P061 | JointNut610_596_2 | Стык 610 · закладная гайка, фиксация требует разработки | A90 | 1 | PLANNED_NOT_EXECUTED
62 | PLBP-D01-P062 | JointScrew610_624_0SocketCut | Стык 610 · M3, условная длина | A90 | 1 | PLANNED_NOT_EXECUTED
63 | PLBP-D01-P063 | JointNut610_624_0 | Стык 610 · закладная гайка, фиксация требует разработки | A90 | 1 | PLANNED_NOT_EXECUTED
64 | PLBP-D01-P064 | JointScrew610_624_1SocketCut | Стык 610 · M3, условная длина | A90 | 1 | PLANNED_NOT_EXECUTED
65 | PLBP-D01-P065 | JointNut610_624_1 | Стык 610 · закладная гайка, фиксация требует разработки | A90 | 1 | PLANNED_NOT_EXECUTED
66 | PLBP-D01-P066 | JointScrew610_624_2SocketCut | Стык 610 · M3, условная длина | A90 | 1 | PLANNED_NOT_EXECUTED
67 | PLBP-D01-P067 | JointNut610_624_2 | Стык 610 · закладная гайка, фиксация требует разработки | A90 | 1 | PLANNED_NOT_EXECUTED
68 | PLBP-D01-P068 | CouplerHole610_624_2 | Стык X610 · внутренняя втулка 40 мм | A90 | 1 | PLANNED_NOT_EXECUTED
69 | PLBP-D01-P069 | JointGasket610 | Стык X610 · прокладка, кандидат | A90 | 1 | PLANNED_NOT_EXECUTED
70 | PLBP-D01-P070 | JointScrew815_801_0SocketCut | Стык 815 · M3, условная длина | A90 | 1 | PLANNED_NOT_EXECUTED
71 | PLBP-D01-P071 | JointNut815_801_0 | Стык 815 · закладная гайка, фиксация требует разработки | A90 | 1 | PLANNED_NOT_EXECUTED
72 | PLBP-D01-P072 | JointScrew815_801_1SocketCut | Стык 815 · M3, условная длина | A90 | 1 | PLANNED_NOT_EXECUTED
73 | PLBP-D01-P073 | JointNut815_801_1 | Стык 815 · закладная гайка, фиксация требует разработки | A90 | 1 | PLANNED_NOT_EXECUTED
74 | PLBP-D01-P074 | JointScrew815_801_2SocketCut | Стык 815 · M3, условная длина | A90 | 1 | PLANNED_NOT_EXECUTED
75 | PLBP-D01-P075 | JointNut815_801_2 | Стык 815 · закладная гайка, фиксация требует разработки | A90 | 1 | PLANNED_NOT_EXECUTED
76 | PLBP-D01-P076 | JointScrew815_829_0SocketCut | Стык 815 · M3, условная длина | A90 | 1 | PLANNED_NOT_EXECUTED
77 | PLBP-D01-P077 | JointNut815_829_0 | Стык 815 · закладная гайка, фиксация требует разработки | A90 | 1 | PLANNED_NOT_EXECUTED
78 | PLBP-D01-P078 | JointScrew815_829_1SocketCut | Стык 815 · M3, условная длина | A90 | 1 | PLANNED_NOT_EXECUTED
79 | PLBP-D01-P079 | JointNut815_829_1 | Стык 815 · закладная гайка, фиксация требует разработки | A90 | 1 | PLANNED_NOT_EXECUTED
80 | PLBP-D01-P080 | JointScrew815_829_2SocketCut | Стык 815 · M3, условная длина | A90 | 1 | PLANNED_NOT_EXECUTED
81 | PLBP-D01-P081 | JointNut815_829_2 | Стык 815 · закладная гайка, фиксация требует разработки | A90 | 1 | PLANNED_NOT_EXECUTED
82 | PLBP-D01-P082 | CouplerHole815_829_2 | Стык X815 · внутренняя втулка 40 мм | A90 | 1 | PLANNED_NOT_EXECUTED
83 | PLBP-D01-P083 | JointGasket815 | Стык X815 · прокладка, кандидат | A90 | 1 | PLANNED_NOT_EXECUTED
84 | PLBP-D01-P084 | JointScrew1090_1076_0SocketCut | Стык 1090 · M3, условная длина | A90 | 1 | PLANNED_NOT_EXECUTED
85 | PLBP-D01-P085 | JointNut1090_1076_0 | Стык 1090 · закладная гайка, фиксация требует разработки | A90 | 1 | PLANNED_NOT_EXECUTED
86 | PLBP-D01-P086 | JointScrew1090_1076_1SocketCut | Стык 1090 · M3, условная длина | A90 | 1 | PLANNED_NOT_EXECUTED
87 | PLBP-D01-P087 | JointNut1090_1076_1 | Стык 1090 · закладная гайка, фиксация требует разработки | A90 | 1 | PLANNED_NOT_EXECUTED
88 | PLBP-D01-P088 | JointScrew1090_1076_2SocketCut | Стык 1090 · M3, условная длина | A90 | 1 | PLANNED_NOT_EXECUTED
89 | PLBP-D01-P089 | JointNut1090_1076_2 | Стык 1090 · закладная гайка, фиксация требует разработки | A90 | 1 | PLANNED_NOT_EXECUTED
90 | PLBP-D01-P090 | JointScrew1090_1104_0SocketCut | Стык 1090 · M3, условная длина | A90 | 1 | PLANNED_NOT_EXECUTED
91 | PLBP-D01-P091 | JointNut1090_1104_0 | Стык 1090 · закладная гайка, фиксация требует разработки | A90 | 1 | PLANNED_NOT_EXECUTED
92 | PLBP-D01-P092 | JointScrew1090_1104_1SocketCut | Стык 1090 · M3, условная длина | A90 | 1 | PLANNED_NOT_EXECUTED
93 | PLBP-D01-P093 | JointNut1090_1104_1 | Стык 1090 · закладная гайка, фиксация требует разработки | A90 | 1 | PLANNED_NOT_EXECUTED
94 | PLBP-D01-P094 | JointScrew1090_1104_2SocketCut | Стык 1090 · M3, условная длина | A90 | 1 | PLANNED_NOT_EXECUTED
95 | PLBP-D01-P095 | JointNut1090_1104_2 | Стык 1090 · закладная гайка, фиксация требует разработки | A90 | 1 | PLANNED_NOT_EXECUTED
96 | PLBP-D01-P096 | CouplerHole1090_1104_2 | Стык X1090 · внутренняя втулка 40 мм | A90 | 1 | PLANNED_NOT_EXECUTED
97 | PLBP-D01-P097 | JointGasket1090 | Стык X1090 · прокладка, кандидат | A90 | 1 | PLANNED_NOT_EXECUTED
98 | PLBP-D01-P098 | JointScrew1190_1176_0SocketCut | Стык 1190 · M3, условная длина | A90 | 1 | PLANNED_NOT_EXECUTED
99 | PLBP-D01-P099 | JointNut1190_1176_0 | Стык 1190 · закладная гайка, фиксация требует разработки | A90 | 1 | PLANNED_NOT_EXECUTED
100 | PLBP-D01-P100 | JointScrew1190_1176_1SocketCut | Стык 1190 · M3, условная длина | A90 | 1 | PLANNED_NOT_EXECUTED
101 | PLBP-D01-P101 | JointNut1190_1176_1 | Стык 1190 · закладная гайка, фиксация требует разработки | A90 | 1 | PLANNED_NOT_EXECUTED
102 | PLBP-D01-P102 | JointScrew1190_1176_2SocketCut | Стык 1190 · M3, условная длина | A90 | 1 | PLANNED_NOT_EXECUTED
103 | PLBP-D01-P103 | JointNut1190_1176_2 | Стык 1190 · закладная гайка, фиксация требует разработки | A90 | 1 | PLANNED_NOT_EXECUTED
104 | PLBP-D01-P104 | JointScrew1190_1204_0SocketCut | Стык 1190 · M3, условная длина | A90 | 1 | PLANNED_NOT_EXECUTED
105 | PLBP-D01-P105 | JointNut1190_1204_0 | Стык 1190 · закладная гайка, фиксация требует разработки | A90 | 1 | PLANNED_NOT_EXECUTED
106 | PLBP-D01-P106 | JointScrew1190_1204_1SocketCut | Стык 1190 · M3, условная длина | A90 | 1 | PLANNED_NOT_EXECUTED
107 | PLBP-D01-P107 | JointNut1190_1204_1 | Стык 1190 · закладная гайка, фиксация требует разработки | A90 | 1 | PLANNED_NOT_EXECUTED
108 | PLBP-D01-P108 | JointScrew1190_1204_2SocketCut | Стык 1190 · M3, условная длина | A90 | 1 | PLANNED_NOT_EXECUTED
109 | PLBP-D01-P109 | JointNut1190_1204_2 | Стык 1190 · закладная гайка, фиксация требует разработки | A90 | 1 | PLANNED_NOT_EXECUTED
110 | PLBP-D01-P110 | CouplerHole1190_1204_2 | Стык X1190 · внутренняя втулка 40 мм | A90 | 1 | PLANNED_NOT_EXECUTED
111 | PLBP-D01-P111 | JointGasket1190 | Стык X1190 · прокладка, кандидат | A90 | 1 | PLANNED_NOT_EXECUTED
112 | PLBP-D01-P112 | ServiceRing0 | Кольцо съёмного лотка Ø93,6 · 1 | A50 | 1 | PLANNED_NOT_EXECUTED
113 | PLBP-D01-P113 | ServiceRing1 | Кольцо съёмного лотка Ø93,6 · 2 | A50 | 1 | PLANNED_NOT_EXECUTED
114 | PLBP-D01-P114 | NoseShellD01 | Обтекатель · полая оболочка | A20 | 1 | PLANNED_NOT_EXECUTED
115 | PLBP-D01-P115 | NoseShoulderD01 | Обтекатель · отдельная посадочная юбка | A20 | 1 | PLANNED_NOT_EXECUTED
116 | PLBP-D01-P116 | NoseBulkhead | Обтекатель · переборка под интерфейс возврата | A20 | 1 | PLANNED_NOT_EXECUTED
117 | PLBP-D01-P117 | NoseEye | Обтекатель · рым, условная геометрия крепежа | A20 | 1 | PLANNED_NOT_EXECUTED
118 | PLBP-D01-P118 | NoseEyeWasher | Обтекатель · шайба рымового узла | A20 | 1 | PLANNED_NOT_EXECUTED
119 | PLBP-D01-P119 | PayloadBody | Макет · оболочка Ø84, общий размер 220 мм | A30 | 1 | PLANNED_NOT_EXECUTED
120 | PLBP-D01-P120 | PayloadCapHoleFront3 | Макет · съёмная торцевая крышка Front | A30 | 1 | PLANNED_NOT_EXECUTED
121 | PLBP-D01-P121 | PayloadCapHoleRear3 | Макет · съёмная торцевая крышка Rear | A30 | 1 | PLANNED_NOT_EXECUTED
122 | PLBP-D01-P122 | PayloadRailBore0R | Макет · монтажная стойка 1 | A30 | 1 | PLANNED_NOT_EXECUTED
123 | PLBP-D01-P123 | PayloadScrewF0 | Макет · винт M2, габарит | A30 | 1 | PLANNED_NOT_EXECUTED
124 | PLBP-D01-P124 | PayloadScrewR0 | Макет · винт M2, габарит | A30 | 1 | PLANNED_NOT_EXECUTED
125 | PLBP-D01-P125 | PayloadRailBore1R | Макет · монтажная стойка 2 | A30 | 1 | PLANNED_NOT_EXECUTED
126 | PLBP-D01-P126 | PayloadScrewF1 | Макет · винт M2, габарит | A30 | 1 | PLANNED_NOT_EXECUTED
127 | PLBP-D01-P127 | PayloadScrewR1 | Макет · винт M2, габарит | A30 | 1 | PLANNED_NOT_EXECUTED
128 | PLBP-D01-P128 | PayloadRailBore2R | Макет · монтажная стойка 3 | A30 | 1 | PLANNED_NOT_EXECUTED
129 | PLBP-D01-P129 | PayloadScrewF2 | Макет · винт M2, габарит | A30 | 1 | PLANNED_NOT_EXECUTED
130 | PLBP-D01-P130 | PayloadScrewR2 | Макет · винт M2, габарит | A30 | 1 | PLANNED_NOT_EXECUTED
131 | PLBP-D01-P131 | PayloadRailBore3R | Макет · монтажная стойка 4 | A30 | 1 | PLANNED_NOT_EXECUTED
132 | PLBP-D01-P132 | PayloadScrewF3 | Макет · винт M2, габарит | A30 | 1 | PLANNED_NOT_EXECUTED
133 | PLBP-D01-P133 | PayloadScrewR3 | Макет · винт M2, габарит | A30 | 1 | PLANNED_NOT_EXECUTED
134 | PLBP-D01-P134 | PayloadCore | Макет · объём собственной системы и балансировки, не разработан | A30 | 1 | PLANNED_NOT_EXECUTED
135 | PLBP-D01-P135 | PayloadSeat | Макет · опорное кольцо внутри втулки стыка | A30 | 1 | PLANNED_NOT_EXECUTED
136 | PLBP-D01-P136 | PayloadGuide0 | Макет · радиальный направляющий башмак 1 | A30 | 1 | PLANNED_NOT_EXECUTED
137 | PLBP-D01-P137 | PayloadGuide1 | Макет · радиальный направляющий башмак 2 | A30 | 1 | PLANNED_NOT_EXECUTED
138 | PLBP-D01-P138 | PayloadGuide2 | Макет · радиальный направляющий башмак 3 | A30 | 1 | PLANNED_NOT_EXECUTED
139 | PLBP-D01-P139 | RecoveryBag | Спасение · оболочка укладочного мешка | A80 | 1 | PLANNED_NOT_EXECUTED
140 | PLBP-D01-P140 | RecoveryBagEnd0 | Спасение · торцевая ткань 1 | A80 | 1 | PLANNED_NOT_EXECUTED
141 | PLBP-D01-P141 | RecoveryBagEnd1 | Спасение · торцевая ткань 2 | A80 | 1 | PLANNED_NOT_EXECUTED
142 | PLBP-D01-P142 | CanopyFold0 | Спасение · складка купола 1 (условная укладка) | A80 | 1 | PLANNED_NOT_EXECUTED
143 | PLBP-D01-P143 | CanopyFold1 | Спасение · складка купола 2 (условная укладка) | A80 | 1 | PLANNED_NOT_EXECUTED
144 | PLBP-D01-P144 | CanopyFold2 | Спасение · складка купола 3 (условная укладка) | A80 | 1 | PLANNED_NOT_EXECUTED
145 | PLBP-D01-P145 | CanopyFold3 | Спасение · складка купола 4 (условная укладка) | A80 | 1 | PLANNED_NOT_EXECUTED
146 | PLBP-D01-P146 | CanopyFold4 | Спасение · складка купола 5 (условная укладка) | A80 | 1 | PLANNED_NOT_EXECUTED
147 | PLBP-D01-P147 | CanopyFold5 | Спасение · складка купола 6 (условная укладка) | A80 | 1 | PLANNED_NOT_EXECUTED
148 | PLBP-D01-P148 | CanopyFold6 | Спасение · складка купола 7 (условная укладка) | A80 | 1 | PLANNED_NOT_EXECUTED
149 | PLBP-D01-P149 | CanopyFold7 | Спасение · складка купола 8 (условная укладка) | A80 | 1 | PLANNED_NOT_EXECUTED
150 | PLBP-D01-P150 | PackingBand0 | Спасение · лента укладки 1 | A80 | 1 | PLANNED_NOT_EXECUTED
151 | PLBP-D01-P151 | PackingBand1 | Спасение · лента укладки 2 | A80 | 1 | PLANNED_NOT_EXECUTED
152 | PLBP-D01-P152 | MainCablePort | Основной борт · корпус концептуального блока | A50 | 1 | PLANNED_NOT_EXECUTED
153 | PLBP-D01-P153 | MainLidD01 | Основной борт · съёмная крышка | A50 | 1 | PLANNED_NOT_EXECUTED
154 | PLBP-D01-P154 | MainPCBPost0 | Основной борт · опора платы 1 | A50 | 1 | PLANNED_NOT_EXECUTED
155 | PLBP-D01-P155 | MainPCBPost1 | Основной борт · опора платы 2 | A50 | 1 | PLANNED_NOT_EXECUTED
156 | PLBP-D01-P156 | MainPCBPost2 | Основной борт · опора платы 3 | A50 | 1 | PLANNED_NOT_EXECUTED
157 | PLBP-D01-P157 | MainPCBPost3 | Основной борт · опора платы 4 | A50 | 1 | PLANNED_NOT_EXECUTED
158 | PLBP-D01-P158 | MainPCBMount3 | Основной борт · проектная плата размещения, не PCB для производства | A50 | 1 | PLANNED_NOT_EXECUTED
159 | PLBP-D01-P159 | MainLayoutMCU | MCU · место на проектной плате, компонент не выбран | A50 | 1 | PLANNED_NOT_EXECUTED
160 | PLBP-D01-P160 | MainLayoutIMU | IMU · место на проектной плате, компонент не выбран | A50 | 1 | PLANNED_NOT_EXECUTED
161 | PLBP-D01-P161 | MainLayoutBarometer | Barometer · место на проектной плате, компонент не выбран | A50 | 1 | PLANNED_NOT_EXECUTED
162 | PLBP-D01-P162 | MainLayoutStorage | Storage · место на проектной плате, компонент не выбран | A50 | 1 | PLANNED_NOT_EXECUTED
163 | PLBP-D01-P163 | MainLayoutRadio | Radio · место на проектной плате, компонент не выбран | A50 | 1 | PLANNED_NOT_EXECUTED
164 | PLBP-D01-P164 | MainPowerSocket | Основной борт · габарит силового соединителя | A50 | 1 | PLANNED_NOT_EXECUTED
165 | PLBP-D01-P165 | RecoveryControlCase | Блок спасения · корпус, отдельная подсистема | A70 | 1 | PLANNED_NOT_EXECUTED
166 | PLBP-D01-P166 | RecoveryControlLid | Блок спасения · крышка | A70 | 1 | PLANNED_NOT_EXECUTED
167 | PLBP-D01-P167 | RecoveryControlPCB | Блок спасения · проектная плата, исполнительная схема не выпущена | A70 | 1 | PLANNED_NOT_EXECUTED
168 | PLBP-D01-P168 | RecoveryLayout0 | Блок спасения · зарезервированное место компонента | A70 | 1 | PLANNED_NOT_EXECUTED
169 | PLBP-D01-P169 | RecoveryLayout1 | Блок спасения · зарезервированное место компонента | A70 | 1 | PLANNED_NOT_EXECUTED
170 | PLBP-D01-P170 | MotorMountD01 | Моторный отсек · монтажная труба | A40 | 1 | PLANNED_NOT_EXECUTED
171 | PLBP-D01-P171 | MotorRingLight02 | Моторный отсек · кольцо с технологическими отверстиями 1 | A40 | 1 | PLANNED_NOT_EXECUTED
172 | PLBP-D01-P172 | MotorRingLight12 | Моторный отсек · кольцо с технологическими отверстиями 2 | A40 | 1 | PLANNED_NOT_EXECUTED
173 | PLBP-D01-P173 | MotorReferenceD01 | K535W · только паспортный габарит покупного двигателя | A40 | 1 | PLANNED_NOT_EXECUTED
174 | PLBP-D01-P174 | AftInterfacePlate | Хвост · ответная плита, удержание конкретного двигателя уточнить | A40 | 1 | PLANNED_NOT_EXECUTED
175 | PLBP-D01-P175 | FinDetailed1 | Стабилизатор 1 · сквозной корень и наружное перо | A40 | 1 | PLANNED_NOT_EXECUTED
176 | PLBP-D01-P176 | FinDetailed2 | Стабилизатор 2 · сквозной корень и наружное перо | A40 | 1 | PLANNED_NOT_EXECUTED
177 | PLBP-D01-P177 | FinDetailed3 | Стабилизатор 3 · сквозной корень и наружное перо | A40 | 1 | PLANNED_NOT_EXECUTED
178 | PLBP-D01-P178 | GuideFootBore0 | Направляющая · площадка по кривизне корпуса 1 | A100 | 1 | PLANNED_NOT_EXECUTED
179 | PLBP-D01-P179 | GuideSpoolBore0 | Направляющая · ползун, проектный габарит под примерку 1 | A100 | 1 | PLANNED_NOT_EXECUTED
180 | PLBP-D01-P180 | GuideBolt0 | Направляющая · крепёж M3, габарит 1 | A100 | 1 | PLANNED_NOT_EXECUTED
181 | PLBP-D01-P181 | GuideFootBore1 | Направляющая · площадка по кривизне корпуса 2 | A100 | 1 | PLANNED_NOT_EXECUTED
182 | PLBP-D01-P182 | GuideSpoolBore1 | Направляющая · ползун, проектный габарит под примерку 2 | A100 | 1 | PLANNED_NOT_EXECUTED
183 | PLBP-D01-P183 | GuideBolt1 | Направляющая · крепёж M3, габарит 2 | A100 | 1 | PLANNED_NOT_EXECUTED
184 | PLBP-D01-P184 | PowerCableSocket1 | Основная батарея · габарит разъёма | A50 | 1 | PLANNED_NOT_EXECUTED
185 | PLBP-D01-P185 | MainHarness0 | Провод питания · трассировка + | A50 | 1 | PLANNED_NOT_EXECUTED
186 | PLBP-D01-P186 | MainHarness1 | Провод питания · трассировка − | A50 | 1 | PLANNED_NOT_EXECUTED
187 | PLBP-D01-P187 | M01FeatherManufacturer | M01 · Feather RP2040, CAD изготовителя Adafruit | A60 | 1 | PLANNED_NOT_EXECUTED

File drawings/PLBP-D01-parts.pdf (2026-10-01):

PLBP-D01-P001 | D01 / DW01 · 01.10.2026

### E01 боковая опора 1

### ПРОЕКТНЫЙ ЧЕРТЁЖ · НОМИНАЛЬНАЯ ГЕОМЕТРИЯ · НЕ ВЫПУЩЕНО В ПРОИЗВОДСТВО

PLBP-SG1 · Супер ГИРД | A3: 420 × 297 мм | Размеры: мм | Печатать 100% | Лист 1/1

Вид по −Z · X/Y · М 1:4

240*

Вид по +Y · X/Z · М 1:4

240*

Вид по −X · Y/Z · М 5:1

4*

8*

Аксонометрия · М 1:2

Проектная деталь · материал и допуски уточнить

1. Размеры номинальные из CAD D01. Общие допуски, шероховатость и посадки не назначены.
2. Масса расчётная; плотность либо назначенная масса взяты из ведомости.
3. Контуры получены проекцией BRep. Перед изготовлением: выпуск допусков, технологии и проверка креплений.

Локальный габарит X × Y × Z: 240 × 4 × 8 мм

Ориентация листа: Rx 0°; затем перенос начала в (825; -44; -4) мм повернутой сборки.

Материал / массовая модель: GFRP assumed rho1.85

Позиция 001 · Кол. 1 · Масса 14.208 г · Тел 1 · Размеры со * — справочные

Утвердил: — | Технология: — | Допуски: —

PLBP-D01-P002 | D01 / DW01 · 01.10.2026

### E01 боковая опора 2

### ПРОЕКТНЫЙ ЧЕРТЁЖ · НОМИНАЛЬНАЯ ГЕОМЕТРИЯ · НЕ ВЫПУЩЕНО В ПРОИЗВОДСТВО

Вид по −Z · X/Y · М 1:4

240*

Вид по +Y · X/Z · М 1:4

240*

Вид по −X · Y/Z · М 5:1

4*

8*

Аксонометрия · М 1:2

Проектная деталь · материал и допуски уточнить

1. Размеры номинальные из CAD D01. Общие допуски, шероховатость и посадки не назначены.
2. Масса расчётная; плотность либо назначенная масса взяты из ведомости.
3. Контуры получены проекцией BRep. Перед изготовлением: выпуск допусков, технологии и проверка креплений.

Локальный габарит X × Y × Z: 240 × 4 × 8 мм

Ориентация листа: Rx 0°; затем перенос начала в (825; 40; -4) мм повернутой сборки.

Материал / массовая модель: GFRP assumed rho1.85

Позиция 002 · Кол. 1 · Масса 14.208 г · Тел 1 · Размеры со * — справочные

PLBP-D01-P003 | D01 / DW01 · 01.10.2026

### Кассета самописца: открытые каналы давления

### ПРОЕКТНЫЙ ЧЕРТЁЖ · НОМИНАЛЬНАЯ ГЕОМЕТРИЯ · НЕ ВЫПУЩЕНО В ПРОИЗВОДСТВО

PLBP-SG1 · Супер ГИРД | A3: 420 × 297 мм | Размеры: мм | Печатать 100% | Лист 1/2

Вид по −Z · X/Y · М 1:2

93*

79*

Вид по +Y · X/Z · М 1:1

93*

23.5*

Вид по −X · Y/Z · М 1:1

79*

23.5*

Аксонометрия · М 1:2

Проектная деталь · материал и допуски уточнить

1. Размеры номинальные из CAD D01. Общие допуски, шероховатость и посадки не назначены.
2. Масса расчётная; плотность либо назначенная масса взяты из ведомости.
3. Контуры получены проекцией BRep. Перед изготовлением: выпуск допусков, технологии и проверка креплений.

Цилиндрические поверхности: 4. Диаметры и оси — на следующих листах; обозначение C01…

Локальный габарит X × Y × Z: 93 × 79 × 23.5 мм

Ориентация листа: Rx 0°; затем перенос начала в (845.5; -39.5; -25) мм повернутой сборки.

Материал / массовая модель: PETG prototype rho1.27

Позиция 003 · Кол. 1 · Масса 30.903 г · Тел 1 · Размеры со * — справочные

PLBP-D01-P003 | D01 / DW01 · 01.10.2026

### Кассета самописца: открытые каналы давления · координаты цилиндрических поверхностей

### ПРОЕКТНЫЙ ЧЕРТЁЖ · НОМИНАЛЬНАЯ ГЕОМЕТРИЯ · НЕ ВЫПУЩЕНО В ПРОИЗВОДСТВО

PLBP-SG1 · Супер ГИРД | A3: 420 × 297 мм | Размеры: мм | Печатать 100% | Лист 2/2

Точки осей и направления заданы в локальной системе первого листа. Ø не является назначением посадки.

Наружная / внутренняя поверхность — классификация геометрии; внутренняя не всегда сквозное отверстие.

ID Тип Ø, мм Точка на оси X / Y / Z, мм Направление оси i / j / k

C01 | внутр. | 3.4 | 10.5 / 4 / 22.25 | 0 / 0 / 1
C02 | внутр. | 3.4 | 10.5 / 75 / 22.25 | 0 / 0 / 1
C03 | внутр. | 3.4 | 82.5 / 4 / 22.25 | 0 / 0 / 1
C04 | внутр. | 3.4 | 82.5 / 75 / 22.25 | 0 / 0 / 1

Точка на оси — проекция центра цилиндрической поверхности на её ось; любая точка L(t)=P+t·a задаёт ту же ось. Для изготовления требуются утверждённые допуски и ограничение поверхности по 3D-модели.

Координатная таблица дополняет виды; глубины глухих отверстий не следует выводить из бесконечной оси.

PLBP-D01-P004 | D01 / DW01 · 01.10.2026

### Решётчатая крышка самописца: фиксация двумя лентами

### ПРОЕКТНЫЙ ЧЕРТЁЖ · НОМИНАЛЬНАЯ ГЕОМЕТРИЯ · НЕ ВЫПУЩЕНО В ПРОИЗВОДСТВО

Вид по −Z · X/Y · М 1:1

93*

39*

Вид по +Y · X/Z · М 1:1

93*

Вид по −X · Y/Z · М 2:1

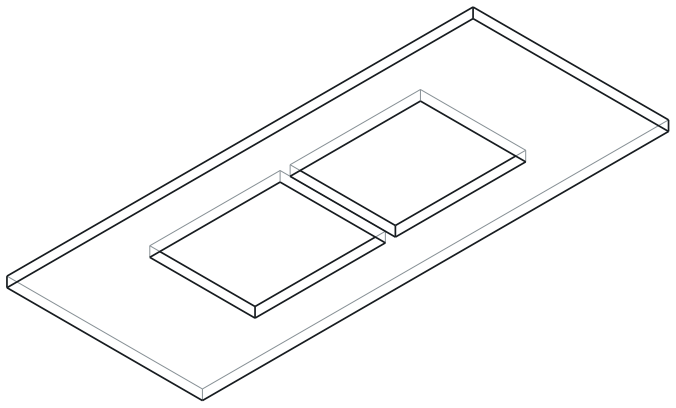
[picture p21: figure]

39*

2*

Аксонометрия · М 1:1

Проектная деталь · материал и допуски уточнить

1. Размеры номинальные из CAD D01. Общие допуски, шероховатость и посадки не назначены.
2. Масса расчётная; плотность либо назначенная масса взяты из ведомости.
3. Контуры получены проекцией BRep. Перед изготовлением: выпуск допусков, технологии и проверка креплений.

Локальный габарит X × Y × Z: 93 × 39 × 2 мм

Ориентация листа: Rx 0°; затем перенос начала в (845.5; -19.5; -27) мм повернутой сборки.

Материал / массовая модель: PETG prototype rho1.27

Позиция 004 · Кол. 1 · Масса 6.439 г · Тел 1 · Размеры со * — справочные

PLBP-D01-P005 | D01 / DW01 · 01.10.2026

### Держатель основной батареи: бортики, вывод провода, две ленты

### ПРОЕКТНЫЙ ЧЕРТЁЖ · НОМИНАЛЬНАЯ ГЕОМЕТРИЯ · НЕ ВЫПУЩЕНО В ПРОИЗВОДСТВО

PLBP-SG1 · Супер ГИРД | A3: 420 × 297 мм | Размеры: мм | Печатать 100% | Лист 1/2

Вид по −Z · X/Y · М 1:2

80*

79*

Вид по +Y · X/Z · М 1:1

80*

8.5*

Вид по −X · Y/Z · М 1:1

79*

8.5*

Аксонометрия · М 1:2

Проектная деталь · материал и допуски уточнить

1. Размеры номинальные из CAD D01. Общие допуски, шероховатость и посадки не назначены.
2. Масса расчётная; плотность либо назначенная масса взяты из ведомости.
3. Контуры получены проекцией BRep. Перед изготовлением: выпуск допусков, технологии и проверка креплений.

Цилиндрические поверхности: 4. Диаметры и оси — на следующих листах; обозначение C01…

Локальный габарит X × Y × Z: 80 × 79 × 8.5 мм

Ориентация листа: Rx 0°; затем перенос начала в (965; -39.5; 1.5) мм повернутой сборки.

Материал / массовая модель: PETG prototype rho1.27

Позиция 005 · Кол. 1 · Масса 19.796 г · Тел 1 · Размеры со * — справочные

PLBP-D01-P005 | D01 / DW01 · 01.10.2026

Держатель основной батареи: бортики, вывод провода, две ленты · координаты цилиндрических поверхностей

### ПРОЕКТНЫЙ ЧЕРТЁЖ · НОМИНАЛЬНАЯ ГЕОМЕТРИЯ · НЕ ВЫПУЩЕНО В ПРОИЗВОДСТВО

PLBP-SG1 · Супер ГИРД | A3: 420 × 297 мм | Размеры: мм | Печатать 100% | Лист 2/2

Точки осей и направления заданы в локальной системе первого листа. Ø не является назначением посадки.

Наружная / внутренняя поверхность — классификация геометрии; внутренняя не всегда сквозное отверстие.

ID Тип Ø, мм Точка на оси X / Y / Z, мм Направление оси i / j / k

C01 | внутр. | 3.4 | 9 / 4 / 1.25 | 0 / 0 / 1
C02 | внутр. | 3.4 | 9 / 75 / 1.25 | 0 / 0 / 1
C03 | внутр. | 3.4 | 71 / 4 / 1.25 | 0 / 0 / 1
C04 | внутр. | 3.4 | 71 / 75 / 1.25 | 0 / 0 / 1

Точка на оси — проекция центра цилиндрической поверхности на её ось; любая точка L(t)=P+t·a задаёт ту же ось. Для изготовления требуются утверждённые допуски и ограничение поверхности по 3D-модели.

Координатная таблица дополняет виды; глубины глухих отверстий не следует выводить из бесконечной оси.

PLBP-D01-P006 | D01 / DW01 · 01.10.2026

### Logger M3×10: условный крепёж 1

### ПРОЕКТНЫЙ ЧЕРТЁЖ · НОМИНАЛЬНАЯ ГЕОМЕТРИЯ · НЕ ВЫПУЩЕНО В ПРОИЗВОДСТВО

Вид по −Z · X/Y · М 10:1

5.6*

5.6*

Вид по +Y · X/Z · М 2:1

5.6*

12.4*

Вид по −X · Y/Z · М 2:1

5.6*

12.4*

Аксонометрия · М 2:1

Условный крепёж · стандарт и длина не утверждены

1. Размеры номинальные из CAD D01. Общие допуски, шероховатость и посадки не назначены.
2. Масса расчётная; плотность либо назначенная масса взяты из ведомости.
3. Резьба условная, без профиля. Подбирать стандартный крепёж по утверждённой спецификации.

Локальный габарит X × Y × Z: 5.6 × 5.6 × 12.4 мм

Ориентация листа: Rx 0°; затем перенос начала в (853.2; -38.3; -6.5) мм повернутой сборки.

Материал / массовая модель: Nominal steel fastener rho7.85

Позиция 006 · Кол. 1 · Масса 1.019 г · Тел 1 · Размеры со * — справочные

PLBP-D01-P007 | D01 / DW01 · 01.10.2026

### Logger гайка M3: цилиндрический габарит 1

### ПРОЕКТНЫЙ ЧЕРТЁЖ · НОМИНАЛЬНАЯ ГЕОМЕТРИЯ · НЕ ВЫПУЩЕНО В ПРОИЗВОДСТВО

Вид по −Z · X/Y · М 5:1

6.4*

6.35*

Вид по +Y · X/Z · М 10:1

6.4*

2.5*

Вид по −X · Y/Z · М 10:1

6.4*

2.5*

Аксонометрия · М 5:1

Условный крепёж · стандарт и длина не утверждены

1. Размеры номинальные из CAD D01. Общие допуски, шероховатость и посадки не назначены.
2. Масса расчётная; плотность либо назначенная масса взяты из ведомости.
3. Резьба условная, без профиля. Подбирать стандартный крепёж по утверждённой спецификации.

Локальный габарит X × Y × Z: 6.4 × 6.4 × 2.5 мм

Ориентация листа: Rx 0°; затем перенос начала в (852.8; -38.7; -6.5) мм повернутой сборки.

Материал / массовая модель: Nominal steel fastener rho7.85

Позиция 007 · Кол. 1 · Масса 0.453 г · Тел 1 · Размеры со * — справочные

PLBP-D01-P008 | D01 / DW01 · 01.10.2026

### Logger M3×10: условный крепёж 2

### ПРОЕКТНЫЙ ЧЕРТЁЖ · НОМИНАЛЬНАЯ ГЕОМЕТРИЯ · НЕ ВЫПУЩЕНО В ПРОИЗВОДСТВО

Вид по −Z · X/Y · М 10:1

5.6*

5.6*

Вид по +Y · X/Z · М 2:1

5.6*

12.4*

Вид по −X · Y/Z · М 2:1

5.6*

12.4*

Аксонометрия · М 2:1

Условный крепёж · стандарт и длина не утверждены

1. Размеры номинальные из CAD D01. Общие допуски, шероховатость и посадки не назначены.
2. Масса расчётная; плотность либо назначенная масса взяты из ведомости.
3. Резьба условная, без профиля. Подбирать стандартный крепёж по утверждённой спецификации.

Локальный габарит X × Y × Z: 5.6 × 5.6 × 12.4 мм

Ориентация листа: Rx 0°; затем перенос начала в (853.2; 32.7; -6.5) мм повернутой сборки.

Материал / массовая модель: Nominal steel fastener rho7.85

Позиция 008 · Кол. 1 · Масса 1.019 г · Тел 1 · Размеры со * — справочные

PLBP-D01-P009 | D01 / DW01 · 01.10.2026

### Logger гайка M3: цилиндрический габарит 2

### ПРОЕКТНЫЙ ЧЕРТЁЖ · НОМИНАЛЬНАЯ ГЕОМЕТРИЯ · НЕ ВЫПУЩЕНО В ПРОИЗВОДСТВО

Вид по −Z · X/Y · М 5:1

6.4*

6.35*

Вид по +Y · X/Z · М 10:1

6.4*

2.5*

Вид по −X · Y/Z · М 10:1

6.4*

2.5*

Аксонометрия · М 5:1

Условный крепёж · стандарт и длина не утверждены

1. Размеры номинальные из CAD D01. Общие допуски, шероховатость и посадки не назначены.
2. Масса расчётная; плотность либо назначенная масса взяты из ведомости.
3. Резьба условная, без профиля. Подбирать стандартный крепёж по утверждённой спецификации.

Локальный габарит X × Y × Z: 6.4 × 6.4 × 2.5 мм

Ориентация листа: Rx 0°; затем перенос начала в (852.8; 32.3; -6.5) мм повернутой сборки.

Материал / массовая модель: Nominal steel fastener rho7.85

Позиция 009 · Кол. 1 · Масса 0.453 г · Тел 1 · Размеры со * — справочные

PLBP-D01-P010 | D01 / DW01 · 01.10.2026

### Logger M3×10: условный крепёж 3

### ПРОЕКТНЫЙ ЧЕРТЁЖ · НОМИНАЛЬНАЯ ГЕОМЕТРИЯ · НЕ ВЫПУЩЕНО В ПРОИЗВОДСТВО

Вид по −Z · X/Y · М 10:1

5.6*

5.6*

Вид по +Y · X/Z · М 2:1

5.6*

12.4*

Вид по −X · Y/Z · М 2:1

5.6*

12.4*

Аксонометрия · М 2:1

Условный крепёж · стандарт и длина не утверждены

1. Размеры номинальные из CAD D01. Общие допуски, шероховатость и посадки не назначены.
2. Масса расчётная; плотность либо назначенная масса взяты из ведомости.
3. Резьба условная, без профиля. Подбирать стандартный крепёж по утверждённой спецификации.

Локальный габарит X × Y × Z: 5.6 × 5.6 × 12.4 мм

Ориентация листа: Rx 0°; затем перенос начала в (925.2; -38.3; -6.5) мм повернутой сборки.

Материал / массовая модель: Nominal steel fastener rho7.85

Позиция 010 · Кол. 1 · Масса 1.019 г · Тел 1 · Размеры со * — справочные

PLBP-D01-P011 | D01 / DW01 · 01.10.2026

### Logger гайка M3: цилиндрический габарит 3

### ПРОЕКТНЫЙ ЧЕРТЁЖ · НОМИНАЛЬНАЯ ГЕОМЕТРИЯ · НЕ ВЫПУЩЕНО В ПРОИЗВОДСТВО

Вид по −Z · X/Y · М 5:1

6.4*

6.35*

Вид по +Y · X/Z · М 10:1

6.4*

2.5*

Вид по −X · Y/Z · М 10:1

6.4*

2.5*

Аксонометрия · М 5:1

Условный крепёж · стандарт и длина не утверждены

1. Размеры номинальные из CAD D01. Общие допуски, шероховатость и посадки не назначены.
2. Масса расчётная; плотность либо назначенная масса взяты из ведомости.
3. Резьба условная, без профиля. Подбирать стандартный крепёж по утверждённой спецификации.

Локальный габарит X × Y × Z: 6.4 × 6.4 × 2.5 мм

Ориентация листа: Rx 0°; затем перенос начала в (924.8; -38.7; -6.5) мм повернутой сборки.

Материал / массовая модель: Nominal steel fastener rho7.85

Позиция 011 · Кол. 1 · Масса 0.453 г · Тел 1 · Размеры со * — справочные

PLBP-D01-P012 | D01 / DW01 · 01.10.2026

### Logger M3×10: условный крепёж 4

### ПРОЕКТНЫЙ ЧЕРТЁЖ · НОМИНАЛЬНАЯ ГЕОМЕТРИЯ · НЕ ВЫПУЩЕНО В ПРОИЗВОДСТВО

Вид по −Z · X/Y · М 10:1

5.6*

5.6*

Вид по +Y · X/Z · М 2:1

5.6*

12.4*

Вид по −X · Y/Z · М 2:1

5.6*

12.4*

Аксонометрия · М 2:1

Условный крепёж · стандарт и длина не утверждены

1. Размеры номинальные из CAD D01. Общие допуски, шероховатость и посадки не назначены.
2. Масса расчётная; плотность либо назначенная масса взяты из ведомости.
3. Резьба условная, без профиля. Подбирать стандартный крепёж по утверждённой спецификации.

Локальный габарит X × Y × Z: 5.6 × 5.6 × 12.4 мм

Ориентация листа: Rx 0°; затем перенос начала в (925.2; 32.7; -6.5) мм повернутой сборки.

Материал / массовая модель: Nominal steel fastener rho7.85

Позиция 012 · Кол. 1 · Масса 1.019 г · Тел 1 · Размеры со * — справочные

PLBP-D01-P013 | D01 / DW01 · 01.10.2026

### Logger гайка M3: цилиндрический габарит 4

### ПРОЕКТНЫЙ ЧЕРТЁЖ · НОМИНАЛЬНАЯ ГЕОМЕТРИЯ · НЕ ВЫПУЩЕНО В ПРОИЗВОДСТВО

Вид по −Z · X/Y · М 5:1

6.4*

6.35*

Вид по +Y · X/Z · М 10:1

6.4*

2.5*

Вид по −X · Y/Z · М 10:1

6.4*

2.5*

Аксонометрия · М 5:1

Условный крепёж · стандарт и длина не утверждены

1. Размеры номинальные из CAD D01. Общие допуски, шероховатость и посадки не назначены.
2. Масса расчётная; плотность либо назначенная масса взяты из ведомости.
3. Резьба условная, без профиля. Подбирать стандартный крепёж по утверждённой спецификации.

Локальный габарит X × Y × Z: 6.4 × 6.4 × 2.5 мм

Ориентация листа: Rx 0°; затем перенос начала в (924.8; 32.3; -6.5) мм повернутой сборки.

Материал / массовая модель: Nominal steel fastener rho7.85

Позиция 013 · Кол. 1 · Масса 0.453 г · Тел 1 · Размеры со * — справочные

PLBP-D01-P014 | D01 / DW01 · 01.10.2026

### Battery M3×10: условный крепёж 1

### ПРОЕКТНЫЙ ЧЕРТЁЖ · НОМИНАЛЬНАЯ ГЕОМЕТРИЯ · НЕ ВЫПУЩЕНО В ПРОИЗВОДСТВО

Вид по −Z · X/Y · М 10:1

5.6*

5.6*

Вид по +Y · X/Z · М 2:1

5.6*

12.4*

Вид по −X · Y/Z · М 2:1

5.6*

12.4*

Аксонометрия · М 2:1

Условный крепёж · стандарт и длина не утверждены

1. Размеры номинальные из CAD D01. Общие допуски, шероховатость и посадки не назначены.
2. Масса расчётная; плотность либо назначенная масса взяты из ведомости.
3. Резьба условная, без профиля. Подбирать стандартный крепёж по утверждённой спецификации.

Локальный габарит X × Y × Z: 5.6 × 5.6 × 12.4 мм

Ориентация листа: Rx 0°; затем перенос начала в (971.2; -38.3; -6) мм повернутой сборки.

Материал / массовая модель: Nominal steel fastener rho7.85

Позиция 014 · Кол. 1 · Масса 1.019 г · Тел 1 · Размеры со * — справочные

PLBP-D01-P015 | D01 / DW01 · 01.10.2026

### Battery гайка M3: цилиндрический габарит 1

### ПРОЕКТНЫЙ ЧЕРТЁЖ · НОМИНАЛЬНАЯ ГЕОМЕТРИЯ · НЕ ВЫПУЩЕНО В ПРОИЗВОДСТВО

Вид по −Z · X/Y · М 5:1

6.4*

6.35*

Вид по +Y · X/Z · М 10:1

6.4*

2.5*

Вид по −X · Y/Z · М 10:1

6.4*

2.5*

Аксонометрия · М 5:1

Условный крепёж · стандарт и длина не утверждены

1. Размеры номинальные из CAD D01. Общие допуски, шероховатость и посадки не назначены.
2. Масса расчётная; плотность либо назначенная масса взяты из ведомости.
3. Резьба условная, без профиля. Подбирать стандартный крепёж по утверждённой спецификации.

Локальный габарит X × Y × Z: 6.4 × 6.4 × 2.5 мм

Ориентация листа: Rx 0°; затем перенос начала в (970.8; -38.7; -4) мм повернутой сборки.

Материал / массовая модель: Nominal steel fastener rho7.85

Позиция 015 · Кол. 1 · Масса 0.453 г · Тел 1 · Размеры со * — справочные

PLBP-D01-P016 | D01 / DW01 · 01.10.2026

### Battery M3×10: условный крепёж 2

### ПРОЕКТНЫЙ ЧЕРТЁЖ · НОМИНАЛЬНАЯ ГЕОМЕТРИЯ · НЕ ВЫПУЩЕНО В ПРОИЗВОДСТВО

Вид по −Z · X/Y · М 10:1

5.6*

5.6*

Вид по +Y · X/Z · М 2:1

5.6*

12.4*

Вид по −X · Y/Z · М 2:1

5.6*

12.4*

Аксонометрия · М 2:1

Условный крепёж · стандарт и длина не утверждены

1. Размеры номинальные из CAD D01. Общие допуски, шероховатость и посадки не назначены.
2. Масса расчётная; плотность либо назначенная масса взяты из ведомости.
3. Резьба условная, без профиля. Подбирать стандартный крепёж по утверждённой спецификации.

Локальный габарит X × Y × Z: 5.6 × 5.6 × 12.4 мм

Ориентация листа: Rx 0°; затем перенос начала в (971.2; 32.7; -6) мм повернутой сборки.

Материал / массовая модель: Nominal steel fastener rho7.85

Позиция 016 · Кол. 1 · Масса 1.019 г · Тел 1 · Размеры со * — справочные

PLBP-D01-P017 | D01 / DW01 · 01.10.2026

### Battery гайка M3: цилиндрический габарит 2

### ПРОЕКТНЫЙ ЧЕРТЁЖ · НОМИНАЛЬНАЯ ГЕОМЕТРИЯ · НЕ ВЫПУЩЕНО В ПРОИЗВОДСТВО

Вид по −Z · X/Y · М 5:1

6.4*

6.35*

Вид по +Y · X/Z · М 10:1

6.4*

2.5*

Вид по −X · Y/Z · М 10:1

6.4*

2.5*

Аксонометрия · М 5:1

Условный крепёж · стандарт и длина не утверждены

1. Размеры номинальные из CAD D01. Общие допуски, шероховатость и посадки не назначены.
2. Масса расчётная; плотность либо назначенная масса взяты из ведомости.
3. Резьба условная, без профиля. Подбирать стандартный крепёж по утверждённой спецификации.

Локальный габарит X × Y × Z: 6.4 × 6.4 × 2.5 мм

Ориентация листа: Rx 0°; затем перенос начала в (970.8; 32.3; -4) мм повернутой сборки.

Материал / массовая модель: Nominal steel fastener rho7.85

Позиция 017 · Кол. 1 · Масса 0.453 г · Тел 1 · Размеры со * — справочные

PLBP-D01-P018 | D01 / DW01 · 01.10.2026

### Battery M3×10: условный крепёж 3

### ПРОЕКТНЫЙ ЧЕРТЁЖ · НОМИНАЛЬНАЯ ГЕОМЕТРИЯ · НЕ ВЫПУЩЕНО В ПРОИЗВОДСТВО

Вид по −Z · X/Y · М 10:1

5.6*

5.6*

Вид по +Y · X/Z · М 2:1

5.6*

12.4*

Вид по −X · Y/Z · М 2:1

5.6*

12.4*

Аксонометрия · М 2:1

Условный крепёж · стандарт и длина не утверждены

1. Размеры номинальные из CAD D01. Общие допуски, шероховатость и посадки не назначены.
2. Масса расчётная; плотность либо назначенная масса взяты из ведомости.
3. Резьба условная, без профиля. Подбирать стандартный крепёж по утверждённой спецификации.

Локальный габарит X × Y × Z: 5.6 × 5.6 × 12.4 мм

Ориентация листа: Rx 0°; затем перенос начала в (1033.2; -38.3; -6) мм повернутой сборки.

Материал / массовая модель: Nominal steel fastener rho7.85

Позиция 018 · Кол. 1 · Масса 1.019 г · Тел 1 · Размеры со * — справочные

PLBP-D01-P019 | D01 / DW01 · 01.10.2026

### Battery гайка M3: цилиндрический габарит 3

### ПРОЕКТНЫЙ ЧЕРТЁЖ · НОМИНАЛЬНАЯ ГЕОМЕТРИЯ · НЕ ВЫПУЩЕНО В ПРОИЗВОДСТВО

Вид по −Z · X/Y · М 5:1

6.4*

6.35*

Вид по +Y · X/Z · М 10:1

6.4*

2.5*

Вид по −X · Y/Z · М 10:1

6.4*

2.5*

Аксонометрия · М 5:1

Условный крепёж · стандарт и длина не утверждены

1. Размеры номинальные из CAD D01. Общие допуски, шероховатость и посадки не назначены.
2. Масса расчётная; плотность либо назначенная масса взяты из ведомости.
3. Резьба условная, без профиля. Подбирать стандартный крепёж по утверждённой спецификации.

Локальный габарит X × Y × Z: 6.4 × 6.4 × 2.5 мм

Ориентация листа: Rx 0°; затем перенос начала в (1032.8; -38.7; -4) мм повернутой сборки.

Материал / массовая модель: Nominal steel fastener rho7.85

Позиция 019 · Кол. 1 · Масса 0.453 г · Тел 1 · Размеры со * — справочные

PLBP-D01-P020 | D01 / DW01 · 01.10.2026

### Battery M3×10: условный крепёж 4

### ПРОЕКТНЫЙ ЧЕРТЁЖ · НОМИНАЛЬНАЯ ГЕОМЕТРИЯ · НЕ ВЫПУЩЕНО В ПРОИЗВОДСТВО

Вид по −Z · X/Y · М 10:1

5.6*

5.6*

Вид по +Y · X/Z · М 2:1

5.6*

12.4*

Вид по −X · Y/Z · М 2:1

5.6*

12.4*

Аксонометрия · М 2:1

Условный крепёж · стандарт и длина не утверждены

1. Размеры номинальные из CAD D01. Общие допуски, шероховатость и посадки не назначены.
2. Масса расчётная; плотность либо назначенная масса взяты из ведомости.
3. Резьба условная, без профиля. Подбирать стандартный крепёж по утверждённой спецификации.

Локальный габарит X × Y × Z: 5.6 × 5.6 × 12.4 мм

Ориентация листа: Rx 0°; затем перенос начала в (1033.2; 32.7; -6) мм повернутой сборки.

Материал / массовая модель: Nominal steel fastener rho7.85

Позиция 020 · Кол. 1 · Масса 1.019 г · Тел 1 · Размеры со * — справочные

PLBP-D01-P021 | D01 / DW01 · 01.10.2026

### Battery гайка M3: цилиндрический габарит 4

### ПРОЕКТНЫЙ ЧЕРТЁЖ · НОМИНАЛЬНАЯ ГЕОМЕТРИЯ · НЕ ВЫПУЩЕНО В ПРОИЗВОДСТВО

Вид по −Z · X/Y · М 5:1

6.4*

6.35*

Вид по +Y · X/Z · М 10:1

6.4*

2.5*

Вид по −X · Y/Z · М 10:1

6.4*

2.5*

Аксонометрия · М 5:1

Условный крепёж · стандарт и длина не утверждены

1. Размеры номинальные из CAD D01. Общие допуски, шероховатость и посадки не назначены.
2. Масса расчётная; плотность либо назначенная масса взяты из ведомости.
3. Резьба условная, без профиля. Подбирать стандартный крепёж по утверждённой спецификации.

Локальный габарит X × Y × Z: 6.4 × 6.4 × 2.5 мм

Ориентация листа: Rx 0°; затем перенос начала в (1032.8; 32.3; -4) мм повернутой сборки.

Материал / массовая модель: Nominal steel fastener rho7.85

Позиция 021 · Кол. 1 · Масса 0.453 г · Тел 1 · Размеры со * — справочные

PLBP-D01-P022 | D01 / DW01 · 01.10.2026

### Самописец организатора · габарит A04

### ПРОЕКТНЫЙ ЧЕРТЁЖ · НОМИНАЛЬНАЯ ГЕОМЕТРИЯ · НЕ ВЫПУЩЕНО В ПРОИЗВОДСТВО

Вид по −Z · X/Y · М 1:1

84*

30*

Вид по +Y · X/Z · М 1:1

84*

18*

Вид по −X · Y/Z · М 2:1

30*

18*

Аксонометрия · М 1:2

Габарит / резерв / условная укладка

1. Размеры номинальные из CAD D01. Общие допуски, шероховатость и посадки не назначены.
2. Масса расчётная; плотность либо назначенная масса взяты из ведомости.
3. Не использовать этот лист для изготовления покупного изделия или раскроя ткани.

Локальный габарит X × Y × Z: 84 × 30 × 18 мм

Ориентация листа: Rx 0°; затем перенос начала в (850; -15; -23.5) мм повернутой сборки.

Материал / массовая модель: Assembly: assigned mass; density N/A

Позиция 022 · Кол. 1 · Масса 30.000 г · Тел 1 · Размеры со * — справочные

PLBP-D01-P023 | D01 / DW01 · 01.10.2026

### Основное питание · габарит A04

### ПРОЕКТНЫЙ ЧЕРТЁЖ · НОМИНАЛЬНАЯ ГЕОМЕТРИЯ · НЕ ВЫПУЩЕНО В ПРОИЗВОДСТВО

Вид по −Z · X/Y · М 1:1

70*

40*

Вид по +Y · X/Z · М 1:1

70*

22*

Вид по −X · Y/Z · М 2:1

40*

22*

Аксонометрия · М 1:2

Габарит / резерв / условная укладка

1. Размеры номинальные из CAD D01. Общие допуски, шероховатость и посадки не назначены.
2. Масса расчётная; плотность либо назначенная масса взяты из ведомости.
3. Не использовать этот лист для изготовления покупного изделия или раскроя ткани.

Локальный габарит X × Y × Z: 70 × 40 × 22 мм

Ориентация листа: Rx 0°; затем перенос начала в (970; -20; 5) мм повернутой сборки.

Материал / массовая модель: Assembly: assigned mass; density N/A

Позиция 023 · Кол. 1 · Масса 100.000 г · Тел 1 · Размеры со * — справочные

PLBP-D01-P024 | D01 / DW01 · 01.10.2026

### E02 опора основного блока: общий крепёж с кассетой самописца

### ПРОЕКТНЫЙ ЧЕРТЁЖ · НОМИНАЛЬНАЯ ГЕОМЕТРИЯ · НЕ ВЫПУЩЕНО В ПРОИЗВОДСТВО

PLBP-SG1 · Супер ГИРД | A3: 420 × 297 мм | Размеры: мм | Печатать 100% | Лист 1/2

Вид по −Z · X/Y · М 1:2

99*

79*

Вид по +Y · X/Z · М 1:1

99*

6.5*

Вид по −X · Y/Z · М 1:1

79*

6.5*

Аксонометрия · М 1:2

Проектная деталь · материал и допуски уточнить

1. Размеры номинальные из CAD D01. Общие допуски, шероховатость и посадки не назначены.
2. Масса расчётная; плотность либо назначенная масса взяты из ведомости.
3. Контуры получены проекцией BRep. Перед изготовлением: выпуск допусков, технологии и проверка креплений.

Цилиндрические поверхности: 8. Диаметры и оси — на следующих листах; обозначение C01…

Локальный габарит X × Y × Z: 99 × 79 × 6.5 мм

Ориентация листа: Rx 0°; затем перенос начала в (848; -39.5; 1.5) мм повернутой сборки.

Материал / массовая модель: PETG prototype rho1.27

Позиция 024 · Кол. 1 · Масса 11.138 г · Тел 1 · Размеры со * — справочные

PLBP-D01-P024 | D01 / DW01 · 01.10.2026

E02 опора основного блока: общий крепёж с кассетой самописца · координаты цилиндрических поверхностей

### ПРОЕКТНЫЙ ЧЕРТЁЖ · НОМИНАЛЬНАЯ ГЕОМЕТРИЯ · НЕ ВЫПУЩЕНО В ПРОИЗВОДСТВО

PLBP-SG1 · Супер ГИРД | A3: 420 × 297 мм | Размеры: мм | Печатать 100% | Лист 2/2

Точки осей и направления заданы в локальной системе первого листа. Ø не является назначением посадки.

Наружная / внутренняя поверхность — классификация геометрии; внутренняя не всегда сквозное отверстие.

ID Тип Ø, мм Точка на оси X / Y / Z, мм Направление оси i / j / k

C01 | внутр. | 3.4 | 8 / 4 / 1 | 0 / 0 / 1
C02 | внутр. | 3.4 | 8 / 75 / 1 | 0 / 0 / 1
C03 | внутр. | 3.4 | 80 / 4 / 1 | 0 / 0 / 1
C04 | внутр. | 3.4 | 80 / 75 / 1 | 0 / 0 / 1
C05 | внутр. | 6.4 | 8 / 4 / 4.25 | 0 / 0 / 1
C06 | внутр. | 6.4 | 8 / 75 / 4.25 | 0 / 0 / 1
C07 | внутр. | 6.4 | 80 / 4 / 4.25 | 0 / 0 / 1
C08 | внутр. | 6.4 | 80 / 75 / 4.25 | 0 / 0 / 1

Точка на оси — проекция центра цилиндрической поверхности на её ось; любая точка L(t)=P+t·a задаёт ту же ось. Для изготовления требуются утверждённые допуски и ограничение поверхности по 3D-модели.

Координатная таблица дополняет виды; глубины глухих отверстий не следует выводить из бесконечной оси.

PLBP-D01-P025 | D01 / DW01 · 01.10.2026

### M01 несущая кассета: электроника, питание, звуковые окна

### ПРОЕКТНЫЙ ЧЕРТЁЖ · НОМИНАЛЬНАЯ ГЕОМЕТРИЯ · НЕ ВЫПУЩЕНО В ПРОИЗВОДСТВО

PLBP-SG1 · Супер ГИРД | A3: 420 × 297 мм | Размеры: мм | Печатать 100% | Лист 1/2

Вид по −Z · X/Y · М 1:2

109*

66*

Вид по +Y · X/Z · М 1:2

109*

34.5*

Вид по −X · Y/Z · М 1:1

66*

34.5*

Аксонометрия · М 1:2

Проектная деталь · материал и допуски уточнить

1. Размеры номинальные из CAD D01. Общие допуски, шероховатость и посадки не назначены.
2. Масса расчётная; плотность либо назначенная масса взяты из ведомости.
3. Контуры получены проекцией BRep. Перед изготовлением: выпуск допусков, технологии и проверка креплений.

Цилиндрические поверхности: 4. Диаметры и оси — на следующих листах; обозначение C01…

Локальный габарит X × Y × Z: 109 × 66 × 34.5 мм

Ориентация листа: Rx 0°; затем перенос начала в (944; -33; -36) мм повернутой сборки.

Материал / массовая модель: PETG prototype rho1.27

Позиция 025 · Кол. 1 · Масса 35.930 г · Тел 1 · Размеры со * — справочные

PLBP-D01-P025 | D01 / DW01 · 01.10.2026

M01 несущая кассета: электроника, питание, звуковые окна · координаты цилиндрических поверхностей
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

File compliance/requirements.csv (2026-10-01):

id | source | clause | requirement | evidence | status | closure_action
R01 | REG | 1.11 | Правила соответствующего сезона | Каталог и 9 PDF повторно проверены 01.10.2026; база XV | EXTERNAL_OPEN | Получить ТЗ следующего сезона; XVI анонсирован, технические правила не найдены.
R02 | REG | 4.3.3 | Допуск состава команды в СГ | Команда школьников; для СГ в положении перечислены другие категории | EXTERNAL_OPEN | Подтвердить допуск у организаторов; не заявлять регистрацию полученной.
R03 | REG | 3;5 | Капитан, руководитель, регистрация и этапы | Организационная структура/заявка не предъявлены | OPEN | Назначить роли и пройти регистрацию по фактическому календарю.
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

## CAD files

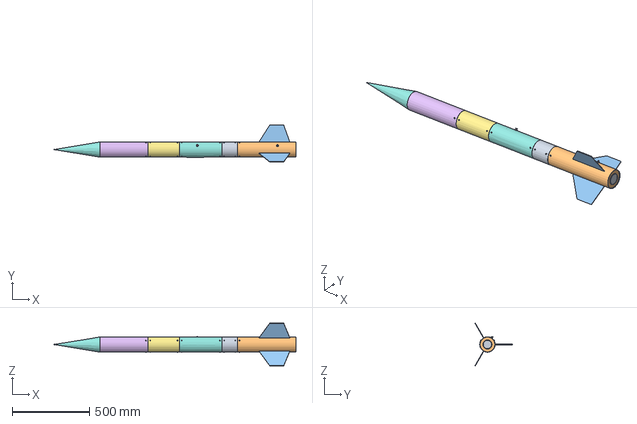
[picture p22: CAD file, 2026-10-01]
model/full-d01/PLBP-SG1-D01-FULL.step
1570.0 x 241.3 x 278.6 mm

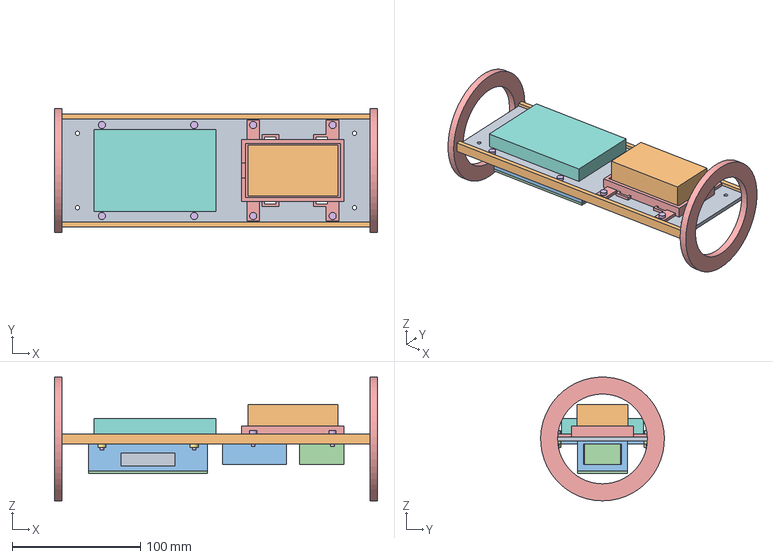
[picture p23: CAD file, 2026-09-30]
model/internal-e01/PLBP-SG1-E01.step
252.0 x 96.6 x 96.5 mm

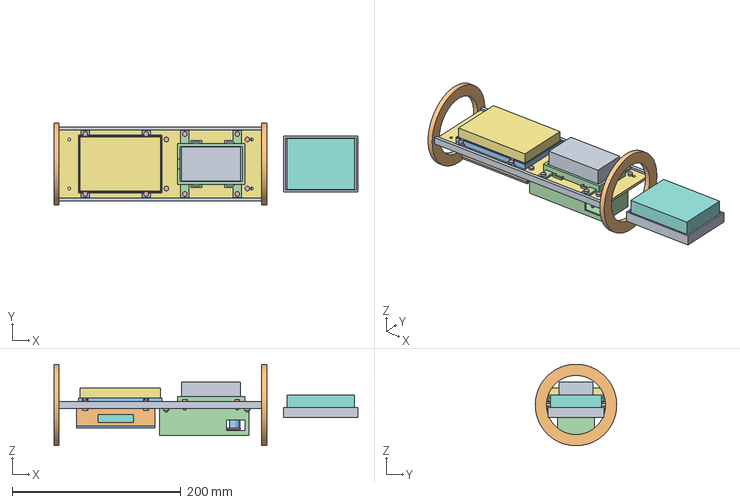
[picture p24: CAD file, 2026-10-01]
model/internal-e02/PLBP-SG1-E02.step
360.0 x 96.6 x 96.5 mm

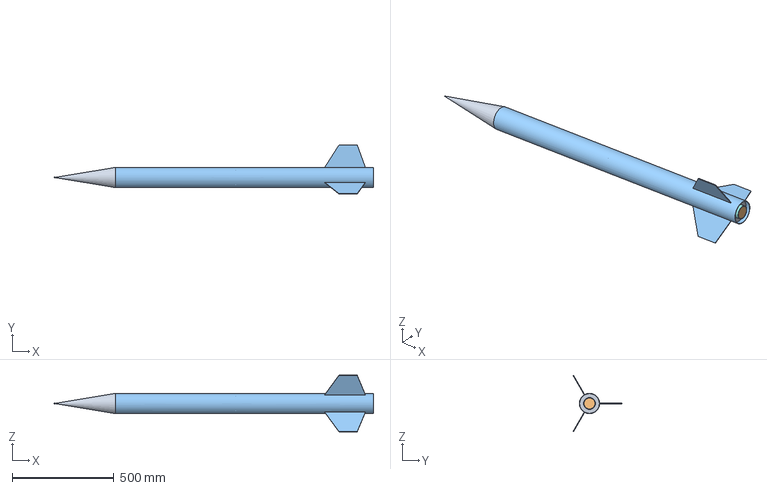
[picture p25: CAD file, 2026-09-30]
model/PLBP-SG1-A04.step
1570.0 x 241.3 x 278.6 mm

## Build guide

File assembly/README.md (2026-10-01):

# План сборки D01 / AS01

[Маршрут сборки CSV](assembly-route.csv) · [все 187 позиций по операциям](component-assignment.csv) · [PDF](assembly-plan.pdf) · [пустой журнал](assembly-record.csv) · [чертежи](../drawings/index.html).

Это план примерки, завершения конструкции и последующей сборки после выпуска соединений. Фактическая сборка не выполнялась. Допуски, моменты затяжки, марки клея и силовые нагрузки не выдуманы: для них установлены контрольные точки H0–H10. В сборочных проверках используется инертный заменитель двигателя. Подключение исполнительных устройств и запуск сюда не входят.

Позиции P001–P187 совпадают с чертежами DW01. Каждая физическая позиция закреплена за одной операцией; шесть нераспределённых массовых бюджетов не считаются отдельными деталями. Полезная нагрузка 1500 г включает собственные элементы макета и зарезервированную внутреннюю систему.

## A00 · Зафиксировать конфигурацию

Предшественники: —. Позиции: общая операция.

Принять D01 и комплект DW01. Проверить сезонное задание, массу макета, двигатель и направляющую. Заполнить лист изменений; назначить ответственных.

Оснастка: Нет.

**Контрольная точка:** H0: силовые чертежи, материалы, допуски и электрическая схема пока не выпущены. До закрытия — только примерочная сборка.

**Результат:** Ведомость ревизий и открытых вопросов подписана командой.

## A10 · Входной контроль

Предшественники: A00. Позиции: общая операция.

Сверить каждую позицию с каталогом P001–P187. Измерить размеры и массу; проверить дефекты, материалы и фактические разъёмы. Наклеить съёмные номера на пакеты деталей.

Оснастка: Штангенциркуль; весы с известной погрешностью; маркировка.

**Контрольная точка:** Не подменять покупной компонент его CAD-габаритом; условные крепежи и складки не изготавливать как показанные тела.

**Результат:** 187 позиций сопоставлены с ведомостью; расхождения записаны.

## A20 · Носовой узел

Предшественники: A10. Позиции: 114–118.

Примерить оболочку, юбку, переборку и интерфейс возврата по листам. Проверить соосность и доступ к креплению. Сохранить возможность осмотра соединения изнутри.

Оснастка: Калибр диаметра; мерительная оснастка.

**Контрольная точка:** H1: соединение переборки, удержание юбки и силовой путь от рымового интерфейса требуют расчёта и утверждения.

**Результат:** Сухая примерка без заеданий; соединения доступны; окончательная фиксация не выполнена до H1.

## A30 · Макет полезной нагрузки

Предшественники: A10. Позиции: 119–138.

Собрать оболочку, торцы и стойки примерочно; проверить положение опоры и башмаков. Зарезервированный объём заполнить только после разработки собственной системы спасения и балансировки.

Оснастка: Калибр Ø84×220; весы.

**Контрольная точка:** H2: согласовать 1000/1500 г и разместить собственное спасение внутри согласованного габарита. PayloadCore — расчётный резерв, не деталь балласта.

**Результат:** Установлен состав макета; закрывается и извлекается без зацепов; фактическая масса учтена вместе со спасением.

## A40 · Моторный отсек и стабилизаторы

Предшественники: A10. Позиции: 170–177.

Использовать инертный размерный заменитель выбранного покупного двигателя. Примерить трубу, кольца, задний интерфейс и три пера с корнями; проверить ориентацию 120° и проход через прорези.

Оснастка: Угловой шаблон; инертный габарит; контрольный калибр.

**Контрольная точка:** H3: удержание двигателя, тепловая защита, крепление колец и корней не выпущены. Не назначать клей/момент затяжки по картинке.

**Результат:** Хвостовая сборка совпадает с интерфейсом поставщика; подтверждён силовой путь и доступ для повторного обслуживания.

## A50 · Основной борт и самописец

Предшественники: A10. Позиции: 001–024, 041, 112–113, 152–164, 184–186.

Установить опоры на лоток; примерить кассету самописца, держатель основного питания, корпус и крышку борта. Вложить фактический самописец или максимальный калибр 85×31×19. Разложить промаркированный жгут; питание отключено.

Оснастка: Калибр прибора; ручной инструмент; бирки проводов.

**Контрольная точка:** H4: выбрать платы, ленты, разъёмы и полную схему. Удержание, ударная и тепловая защита прибора требуют подтверждения.

**Результат:** Нет перекрытия каналов давления и защемления проводов; USB/память и крепёж доступны.

## A60 · Автономная кассета поиска M01

Предшественники: A10. Позиции: 025–040, 042–049, 187.

Примерить кассету, ложемент, крышку батареи, полку, плату Feather и излучатель. Проверить полярность по схеме и документации реальных компонентов; цепь питания соединить только на контролируемом стенде после осмотра.

Оснастка: Реальные платы и батарея; мультиметр; стенд M01.

**Контрольная точка:** H5: наружный звуковой тракт, доступ выключателя/индикатора и аппаратная проверка M01 открыты. Внутренние окна не обеспечивают звук снаружи.

**Результат:** Кабели не тянут разъёмы; батарея не обжата; программа проходит аппаратные проверки; звук проверен в закрытом корпусе.

## A70 · Блок управления спасением

Предшественники: A10. Позиции: 050, 165–169.

Примерить опору, корпус, крышку и плату размещения. После выбора аппаратуры проверить разъёмы и блокировки на безопасных светодиодных эквивалентах исполнительных каналов.

Оснастка: Макеты разъёмов; LED-стенд.

**Контрольная точка:** H6: законченная схема, питание и исполнительные интерфейсы не разработаны. Концептуальная плата не является готовым контроллером.

**Результат:** Подтверждена таблица состояний и отсутствие команды при блокировке; результаты записаны.

## A80 · Система спасения

Предшественники: A20,A30,A40. Позиции: 139–151.

По утверждённому проекту примерить реальные купола, фалы и точки крепления носителя и макета. Проверить независимость двух комплектов, порядок укладки и выход без зацепов на инертном стенде.

Оснастка: Реальные купола/фалы; измеритель усилия; видео.

**Контрольная точка:** H7: раскрой, фалы, раскрытие, отделение и допустимые усилия не выпущены. Восемь складок CAD — иллюстрация, не инструкция укладки.

**Результат:** Есть согласованный состав и проверенные крепления; измерена укладка и усилие извлечения.

## A90 · Корпус и стыки

Предшественники: A20,A30,A40,A50,A60,A70,A80. Позиции: 051–111.

Примерить секции и втулки по станциям X610/815/1090/1190. До закрытия проверить доступ к ответным элементам крепежа. Провести примерку кассеты через внутренние втулки и смену батарей. Финальное закрытие — после A110.

Оснастка: Калибры; инструмент под выбранный крепёж; секундомер.

**Контрольная точка:** H8: закладные гайки и их фиксация открыты. Радиальные зазоры 0,3/0,2 мм номинальные, без утверждённых допусков.

**Результат:** Нет усилий от перекоса, повреждений и зажатого жгута; определён фактический порядок установки закладных.

## A100 · Направляющие

Предшественники: A40,A90. Позиции: 178–183.

Примерить площадки и ползуны к реальной рельсе. Сверить станции X930/1450 и угол 60°; проверить проход инертной сборки по всей рабочей длине.

Оснастка: Рельса организаторов либо согласованный образец.

**Контрольная точка:** H9: CAD-ползун не гарантирует совместимость с Т-пазом 30×30. Окончательная геометрия зависит от рельсы.

**Результат:** Проход без заеданий; крепление проверено; изменения перенесены в CAD и расчёт массы.

## A110 · Проверка перед закрытием

Предшественники: A50,A60,A70,A80,A90,A100. Позиции: общая операция.

Осмотреть все соединения, кабели, маркировку и крепёж; сфотографировать внутренность. Проверить изоляцию жгута и отсутствие посторонних предметов. После проверки отключить стендовое питание и закрыть отсеки по утверждённой карте крепежа.

Оснастка: Карта соединений; мультиметр; фотопротокол.

**Контрольная точка:** Ни одна открытая H1–H9 не может быть закрыта фактом красивой сборки. Значения затяжки назначаются только после выбора соединений.

**Результат:** Контрольная ведомость подписана; все изменения и доступ к батареям проверены.

## A120 · Масса, CG и обслуживание

Предшественники: A110. Позиции: общая операция.

Взвесить завершённую инертную конфигурацию, определить CG повторными балансировками. Выполнить три замены батареи с таймером; перенести измеренные данные в ведомость и ORK.

Оснастка: Весы; опоры для балансировки; секундомер.

**Контрольная точка:** Результаты симуляции со справочным двигателем не заменяют пересчёт под фактический мотор и массу.

**Результат:** Каждая смена батареи ≤5 мин; масса/CG имеют оценку погрешности; ORK соответствует конфигурации.

## A130 · Наземная квалификация и комплектность

Предшественники: A120. Позиции: общая операция.

Выполнить программу наземных проверок: питание, запись/радио, давление, M01, соединения, извлечение и спасение. Обновить документацию и предъявить изделие комиссии. Двигатель и пусковые операции — только по отдельной согласованной процедуре и инструкции изготовителя.

Оснастка: Утверждённые стенды; журнал испытаний.

**Контрольная точка:** H10: физических испытаний и допуска нет. Не переходить от примерки непосредственно к запуску.

**Результат:** Есть свидетельства выполнения требований, закрыты замечания и определена готовность к повторному применению.

## Обслуживание и повторная сборка

Сначала фиксировать состояние и отключать питание по утверждённой электрической процедуре. Разбирать в обратном порядке, сохраняя номера деталей и осмотр креплений; батареи не извлекать за провода. После вмешательства повторить проверки затронутых цепей и соединений. После каждого испытания регистрировать повреждения, изменения массы/CG, состояние корпуса, корней стабилизаторов, фалов и швов. Решение о втором пуске опирается на осмотр и результаты испытаний, а не на формальное наличие требования двух запусков.

[Сверка с регламентом](../compliance/README.md).

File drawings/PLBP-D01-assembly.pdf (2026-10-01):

PLBP-D01-GA01 | D01 / DW01 · 01.10.2026

Ракета в сборе · габаритный чертёж

ПРОЕКТНЫЙ ЧЕРТЁЖ · НОМИНАЛЬНАЯ ГЕОМЕТРИЯ · НЕ ВЫПУЩЕНО В ПРОИЗВОДСТВО

PLBP-SG1 · Супер ГИРД | A3: 420 × 297 мм | Размеры: мм | Печатать 100% | Лист 1/2

Вид по −Z · X/Y · М 1:5

1570*

241.3*

Вид по +Y · X/Z · М 1:10

Вид с хвоста · Y/Z · М 1:5

241.3*

278.63*

Основные размеры: L1570; корпус Ø100 / Ø97; длина носа 300; 3 пера через 120°; огибающий Ø320.

Масса 6136,190 г; CG X943,921 мм от вершины. Полезная нагрузка 1500 г. Двигатель — покупной габарит. Показаны корпус, хвост, наружный крепёж и направляющие; внутренние позиции — в сечении и спецификации.

Габариты и центровка расчётные. Общий чертёж не задаёт кинематику отделения и систему спасения.

PLBP-D01-GA02 | D01 / DW01 · 01.10.2026

Сборка · действительное сечение Z=0 и станции отсеков

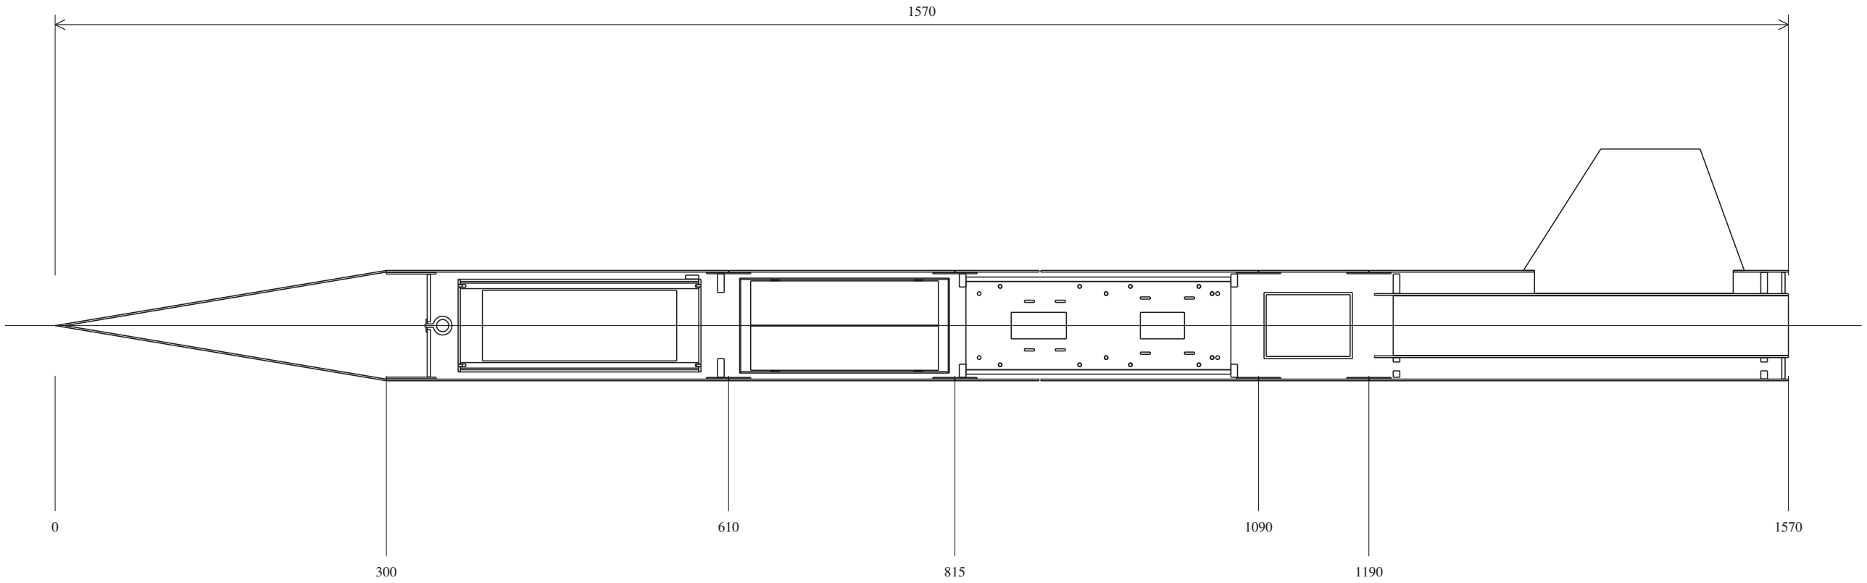
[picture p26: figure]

ПРОЕКТНЫЙ ЧЕРТЁЖ · НОМИНАЛЬНАЯ ГЕОМЕТРИЯ · НЕ ВЫПУЩЕНО В ПРОИЗВОДСТВО

PLBP-SG1 · Супер ГИРД | A3: 420 × 297 мм | Размеры: мм | Печатать 100% | Лист 2/2

Нос
X0…300
Поз. 114–118

Макет
X365…585
Поз. 119–138

Укладка
X620…810
Поз. 139–151

Борт E02/M01
X819…1071
Поз. 001–050, 152–164, 187

Контроллер
X1091…1179
Поз. 165–169

Мотор/хвост
X1195…1570
Поз. 170–183

Плоскость Z=0 пересекает только лежащие в ней детали. Компоненты вне плоскости здесь не показаны. Полный состав — 187 позиций спецификации; линии сечения рассчитаны из исходной CAD.

Общие базы сборки: начало X=0 — вершина; X направлен к хвосту. Y/Z — поперечные оси CAD. Все станции справочные. Втулки и крепёж показаны номинально; способы фиксации и силовые допуски ещё не утверждены.

Массовые резервы без геометрии отдельно в parts.csv основной модели; листы на них не создаются.

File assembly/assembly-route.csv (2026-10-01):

step | title | depends_on | operation | tools | hold_point | acceptance | positions | status
A00 | Зафиксировать конфигурацию | — | Принять D01 и комплект DW01. Проверить сезонное задание, массу макета, двигатель и направляющую. Заполнить лист изменений; назначить ответственных. | Нет | H0: силовые чертежи, материалы, допуски и электрическая схема пока не выпущены. До закрытия — только примерочная сборка. | Ведомость ревизий и открытых вопросов подписана командой. |  | PLANNED_NOT_EXECUTED
A10 | Входной контроль | A00 | Сверить каждую позицию с каталогом P001–P187. Измерить размеры и массу; проверить дефекты, материалы и фактические разъёмы. Наклеить съёмные номера на пакеты деталей. | Штангенциркуль; весы с известной погрешностью; маркировка | Не подменять покупной компонент его CAD-габаритом; условные крепежи и складки не изготавливать как показанные тела. | 187 позиций сопоставлены с ведомостью; расхождения записаны. |  | PLANNED_NOT_EXECUTED
A20 | Носовой узел | A10 | Примерить оболочку, юбку, переборку и интерфейс возврата по листам. Проверить соосность и доступ к креплению. Сохранить возможность осмотра соединения изнутри. | Калибр диаметра; мерительная оснастка | H1: соединение переборки, удержание юбки и силовой путь от рымового интерфейса требуют расчёта и утверждения. | Сухая примерка без заеданий; соединения доступны; окончательная фиксация не выполнена до H1. | 114;115;116;117;118 | PLANNED_NOT_EXECUTED
A30 | Макет полезной нагрузки | A10 | Собрать оболочку, торцы и стойки примерочно; проверить положение опоры и башмаков. Зарезервированный объём заполнить только после разработки собственной системы спасения и балансировки. | Калибр Ø84×220; весы | H2: согласовать 1000/1500 г и разместить собственное спасение внутри согласованного габарита. PayloadCore — расчётный резерв, не деталь балласта. | Установлен состав макета; закрывается и извлекается без зацепов; фактическая масса учтена вместе со спасением. | 119;120;121;122;123;124;125;126;127;128;129;130;131;132;133;134;135;136;137;138 | PLANNED_NOT_EXECUTED
A40 | Моторный отсек и стабилизаторы | A10 | Использовать инертный размерный заменитель выбранного покупного двигателя. Примерить трубу, кольца, задний интерфейс и три пера с корнями; проверить ориентацию 120° и проход через прорези. | Угловой шаблон; инертный габарит; контрольный калибр | H3: удержание двигателя, тепловая защита, крепление колец и корней не выпущены. Не назначать клей/момент затяжки по картинке. | Хвостовая сборка совпадает с интерфейсом поставщика; подтверждён силовой путь и доступ для повторного обслуживания. | 170;171;172;173;174;175;176;177 | PLANNED_NOT_EXECUTED
A50 | Основной борт и самописец | A10 | Установить опоры на лоток; примерить кассету самописца, держатель основного питания, корпус и крышку борта. Вложить фактический самописец или максимальный калибр 85×31×19. Разложить промаркированный жгут; питание отключено. | Калибр прибора; ручной инструмент; бирки проводов | H4: выбрать платы, ленты, разъёмы и полную схему. Удержание, ударная и тепловая защита прибора требуют подтверждения. | Нет перекрытия каналов давления и защемления проводов; USB/память и крепёж доступны. | 001;002;003;004;005;006;007;008;009;010;011;012;013;014;015;016;017;018;019;020;021;022;023;024;041;112;113;152;153;154;155;156;157;158;159;160;161;162;163;164;184;185;186 | PLANNED_NOT_EXECUTED
A60 | Автономная кассета поиска M01 | A10 | Примерить кассету, ложемент, крышку батареи, полку, плату Feather и излучатель. Проверить полярность по схеме и документации реальных компонентов; цепь питания соединить только на контролируемом стенде после осмотра. | Реальные платы и батарея; мультиметр; стенд M01 | H5: наружный звуковой тракт, доступ выключателя/индикатора и аппаратная проверка M01 открыты. Внутренние окна не обеспечивают звук снаружи. | Кабели не тянут разъёмы; батарея не обжата; программа проходит аппаратные проверки; звук проверен в закрытом корпусе. | 025;026;027;028;029;030;031;032;033;034;035;036;037;038;039;040;042;043;044;045;046;047;048;049;187 | PLANNED_NOT_EXECUTED
A70 | Блок управления спасением | A10 | Примерить опору, корпус, крышку и плату размещения. После выбора аппаратуры проверить разъёмы и блокировки на безопасных светодиодных эквивалентах исполнительных каналов. | Макеты разъёмов; LED-стенд | H6: законченная схема, питание и исполнительные интерфейсы не разработаны. Концептуальная плата не является готовым контроллером. | Подтверждена таблица состояний и отсутствие команды при блокировке; результаты записаны. | 050;165;166;167;168;169 | PLANNED_NOT_EXECUTED
A80 | Система спасения | A20,A30,A40 | По утверждённому проекту примерить реальные купола, фалы и точки крепления носителя и макета. Проверить независимость двух комплектов, порядок укладки и выход без зацепов на инертном стенде. | Реальные купола/фалы; измеритель усилия; видео | H7: раскрой, фалы, раскрытие, отделение и допустимые усилия не выпущены. Восемь складок CAD — иллюстрация, не инструкция укладки. | Есть согласованный состав и проверенные крепления; измерена укладка и усилие извлечения. | 139;140;141;142;143;144;145;146;147;148;149;150;151 | PLANNED_NOT_EXECUTED
A90 | Корпус и стыки | A20,A30,A40,A50,A60,A70,A80 | Примерить секции и втулки по станциям X610/815/1090/1190. До закрытия проверить доступ к ответным элементам крепежа. Провести примерку кассеты через внутренние втулки и смену батарей. Финальное закрытие — после A110. | Калибры; инструмент под выбранный крепёж; секундомер | H8: закладные гайки и их фиксация открыты. Радиальные зазоры 0,3/0,2 мм номинальные, без утверждённых допусков. | Нет усилий от перекоса, повреждений и зажатого жгута; определён фактический порядок установки закладных. | 051;052;053;054;055;056;057;058;059;060;061;062;063;064;065;066;067;068;069;070;071;072;073;074;075;076;077;078;079;080;081;082;083;084;085;086;087;088;089;090;091;092;093;094;095;096;097;098;099;100;101;102;103;104;105;106;107;108;109;110;111 | PLANNED_NOT_EXECUTED
A100 | Направляющие | A40,A90 | Примерить площадки и ползуны к реальной рельсе. Сверить станции X930/1450 и угол 60°; проверить проход инертной сборки по всей рабочей длине. | Рельса организаторов либо согласованный образец | H9: CAD-ползун не гарантирует совместимость с Т-пазом 30×30. Окончательная геометрия зависит от рельсы. | Проход без заеданий; крепление проверено; изменения перенесены в CAD и расчёт массы. | 178;179;180;181;182;183 | PLANNED_NOT_EXECUTED
A110 | Проверка перед закрытием | A50,A60,A70,A80,A90,A100 | Осмотреть все соединения, кабели, маркировку и крепёж; сфотографировать внутренность. Проверить изоляцию жгута и отсутствие посторонних предметов. После проверки отключить стендовое питание и закрыть отсеки по утверждённой карте крепежа. | Карта соединений; мультиметр; фотопротокол | Ни одна открытая H1–H9 не может быть закрыта фактом красивой сборки. Значения затяжки назначаются только после выбора соединений. | Контрольная ведомость подписана; все изменения и доступ к батареям проверены. |  | PLANNED_NOT_EXECUTED
A120 | Масса, CG и обслуживание | A110 | Взвесить завершённую инертную конфигурацию, определить CG повторными балансировками. Выполнить три замены батареи с таймером; перенести измеренные данные в ведомость и ORK. | Весы; опоры для балансировки; секундомер | Результаты симуляции со справочным двигателем не заменяют пересчёт под фактический мотор и массу. | Каждая смена батареи ≤5 мин; масса/CG имеют оценку погрешности; ORK соответствует конфигурации. |  | PLANNED_NOT_EXECUTED
A130 | Наземная квалификация и комплектность | A120 | Выполнить программу наземных проверок: питание, запись/радио, давление, M01, соединения, извлечение и спасение. Обновить документацию и предъявить изделие комиссии. Двигатель и пусковые операции — только по отдельной согласованной процедуре и инструкции изготовителя. | Утверждённые стенды; журнал испытаний | H10: физических испытаний и допуска нет. Не переходить от примерки непосредственно к запуску. | Есть свидетельства выполнения требований, закрыты замечания и определена готовность к повторному применению. |  | PLANNED_NOT_EXECUTED

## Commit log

2026-09-30 Publish PLBP-SG1 A04 team results
    [PLBP-SG1-A04.step]
2026-09-30 Add verified OpenRocket scenarios and flight engineering results
    [calm.csv, fine_step.csv, mass-properties.csv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]
2026-09-30 Add E01 internal fit prototype and OR02 flight sensitivity results
    [PLBP-SG1-E01.step, parts.csv, summary.csv]
2026-10-01 Add E02 interior, M01 search mission prototype and OR03 results
    [PLBP-SG1-E02.step, e02.csv, energy.csv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]
2026-10-01 Add complete detailed D01 rocket assembly with section and exploded views
    [PLBP-SG1-D01-FULL.step, mass-totals.csv, parts.csv]
2026-10-01 Improve D01 viewer and publish current-mass OR04 simulations and readiness review
    [calm.csv, engineering.csv, fine.csv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]
2026-10-01 Publish D01 vector drawings for all 187 positions, assembly route and regulation audit
    [assembly-record.csv, assembly-route.csv, catalog.csv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]
